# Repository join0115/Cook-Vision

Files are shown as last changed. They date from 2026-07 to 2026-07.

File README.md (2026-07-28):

# 시각장애인용 요리 보조 안경 (YOLO 기반)

대학교 졸업작품(캡스톤 디자인)으로 제작한 프로젝트입니다. 시각은 인간 감각 수용체의
약 70%를 차지하는 가장 중요한 감각이지만, 시각장애인은 그 정보의 부재로 스스로 요리하는
데 어려움을 겪습니다. 이에 안경에 부착한 카메라 영상을 YOLO로 분석해 조리대 위 재료를
인식하고, 사용자가 음성으로 "빵 어디 있어?"라고 물으면 손을 기준으로 몇 시 방향에 있는지
음성으로 안내함으로써, 타인의 도움 없이도 자율적으로 요리할 수 있도록 하는 것을
목표로 했습니다.

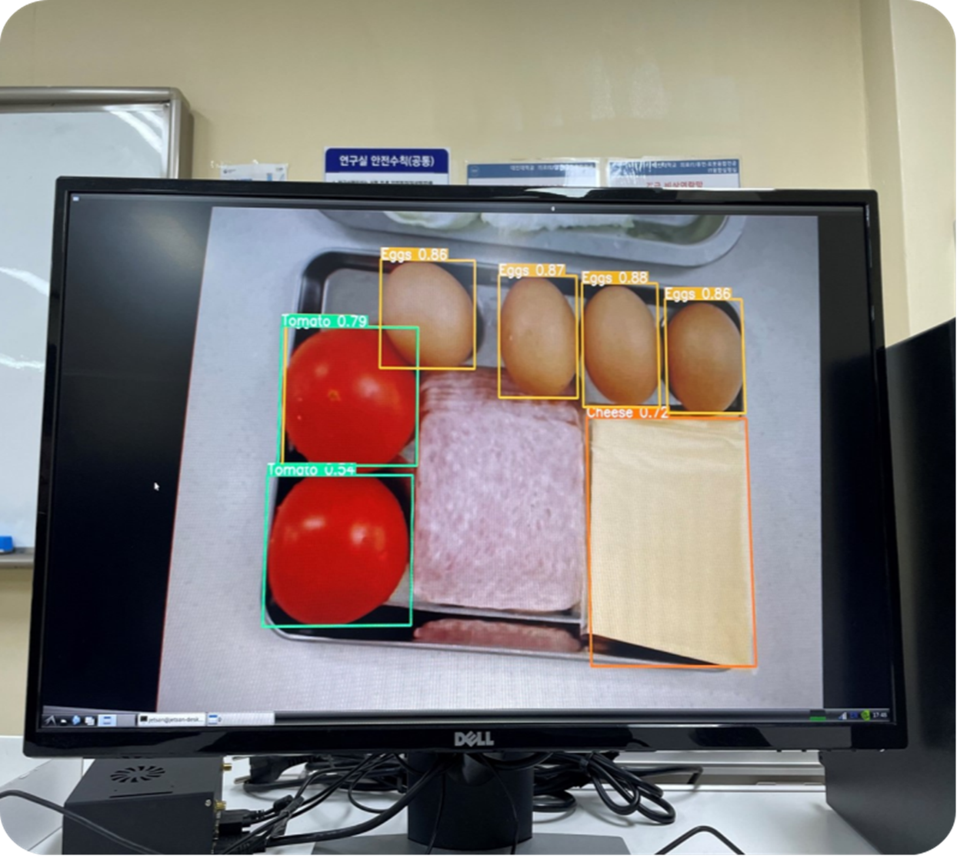
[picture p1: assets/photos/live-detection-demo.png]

*실제 젯슨나노 화면에 라이브로 뜬 YOLOv5 탐지 결과입니다 — 토마토/계란/치즈를 실시간으로 인식하고 있습니다.*
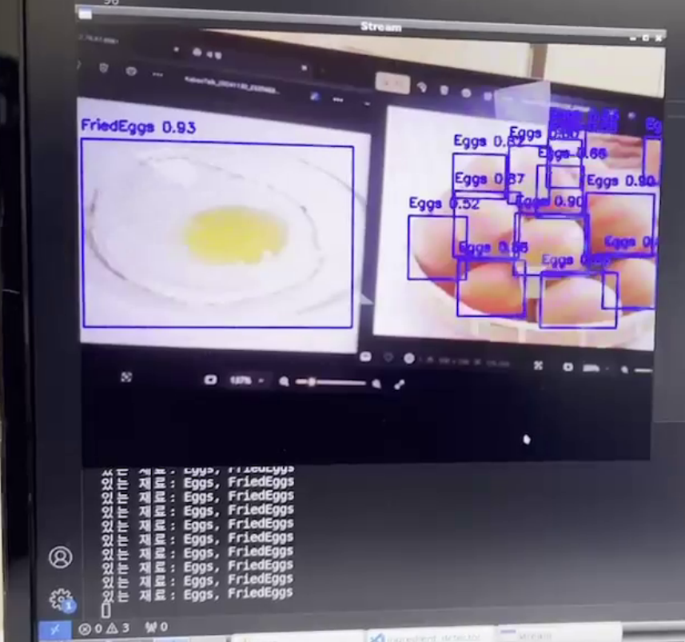
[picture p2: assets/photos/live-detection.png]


## 이 저장소에 대해

원본 프로젝트는 Jetson Nano + Raspberry Pi 두 대의 임베디드 보드에서 동작했는데, 두 보드
모두 하드웨어 오류가 발생하면서 실제 구동 환경과 최신 실행 이력을 잃어버렸습니다.
개발 과정에서 남겨둔 소스 코드 사본이 남아있어, 그것을 다시 분석해서 정리했습니다.

**정리 원칙**: 실제로는 동작하지 않았던 부분을 동작하는 것처럼 꾸미지 않았습니다. 검증
가능한 핵심 기능(`jetson/`, `pi/`)과, 개발 과정에서 시도했지만 완성하지 못한 프로토타입
(`experiments/`)을 명확히 구분했습니다. 무엇을 고쳤고 무엇을 원본 그대로 남겼는지는
[docs/KNOWN_ISSUES.md](./docs/KNOWN_ISSUES.md)에 기록했습니다.

## 기술 스택

- **컴퓨터 비전**: YOLOv5 (커스텀 학습, 클래스: hand/bread/cheese/eggs/friedeggs/ham/lettuce/tomato), OpenCV, PyTorch
- **음성 인식**: Google Cloud Speech-to-Text (스트리밍)
- **웨이크워드 감지**: Picovoice Porcupine
- **음성 출력**: espeak-ng TTS, ALSA(aplay) 기반 사전 녹음 음성 재생
- **통신**: Python 표준 `socket` (TCP) — Jetson Nano ↔ Raspberry Pi
- **하드웨어**: Raspberry Pi(카메라 + ReSpeaker 2 Mics Pi HAT, motionEye로 영상 송출 겸 음성 I/O 담당) + Jetson Nano(스트림을 받아 YOLO 연산만 전담)

## 폴더 구조

```
portfolio/
├── jetson/            # 젯슨나노: YOLO 탐지 + 소켓 서버 (검증된 핵심 기능)
├── pi/                # 라즈베리파이: 음성 인식/출력 + 소켓 클라이언트 (검증된 핵심 기능)
├── experiments/        # 개발 과정 중 시도했던 프로토타입/테스트 (미완성, 각 파일에 이유 명시)
├── assets/
│   ├── voice/         # 음성 안내 mp3/wav 에셋
│   ├── photos/        # 실물/실행 화면 사진
│   └── 3d-model/      # 안경 프레임 3D 모델 (Fusion 360 / STEP / STL) + 렌더 이미지
└── docs/
    ├── ARCHITECTURE.md   # 시스템 구성도 및 실제 검증된 흐름 vs 미완성 흐름
    └── KNOWN_ISSUES.md   # 발견한 버그, 보안 스크러빙 내역, 구조적 문제 기록
```

자세한 시스템 흐름은 [docs/ARCHITECTURE.md](./docs/ARCHITECTURE.md)를 참고해 주세요.

## 사진 & 3D 모델

| | |
|---|---|
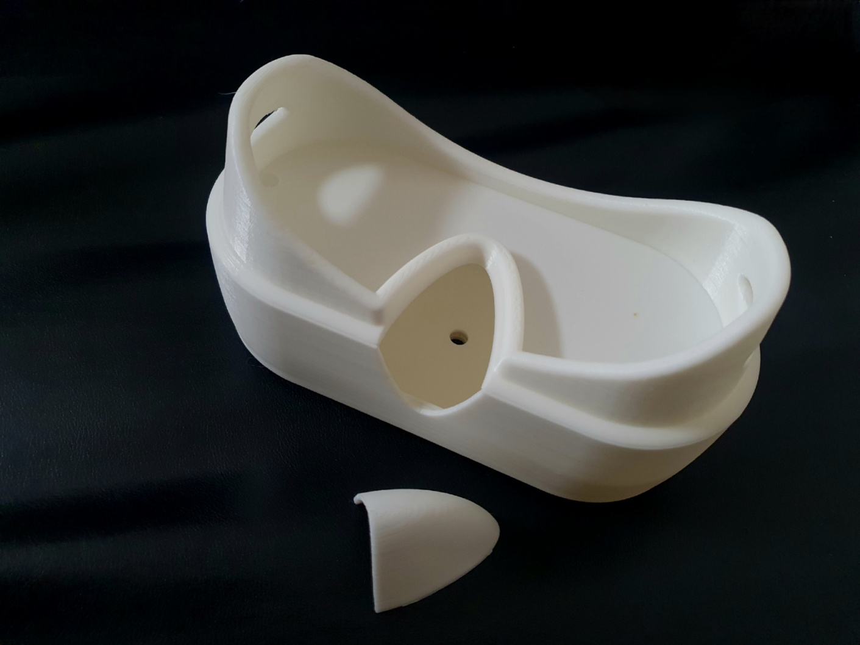
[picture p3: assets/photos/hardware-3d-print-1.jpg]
3D 프린트 출력물 1
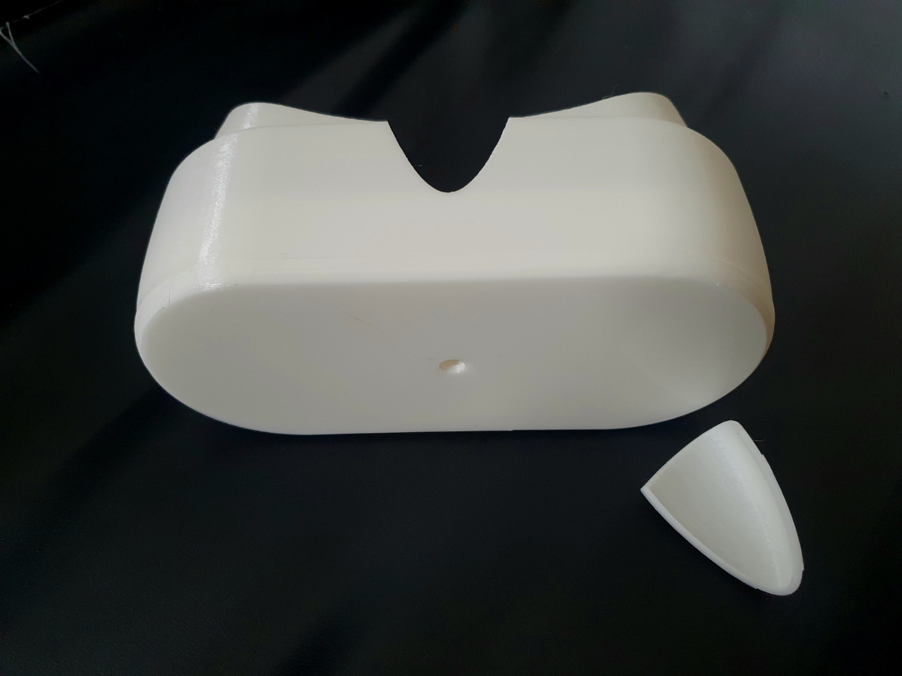
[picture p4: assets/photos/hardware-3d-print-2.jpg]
3D 프린트 출력물 2
|  |  |

3D 프린터로 출력한 안경 프레임 실물입니다. 설계 파일(Fusion 360/STEP/STL)과 렌더 이미지는
[assets/3d-model/](./assets/3d-model/)에 있습니다.

실제 착용한 모습입니다.

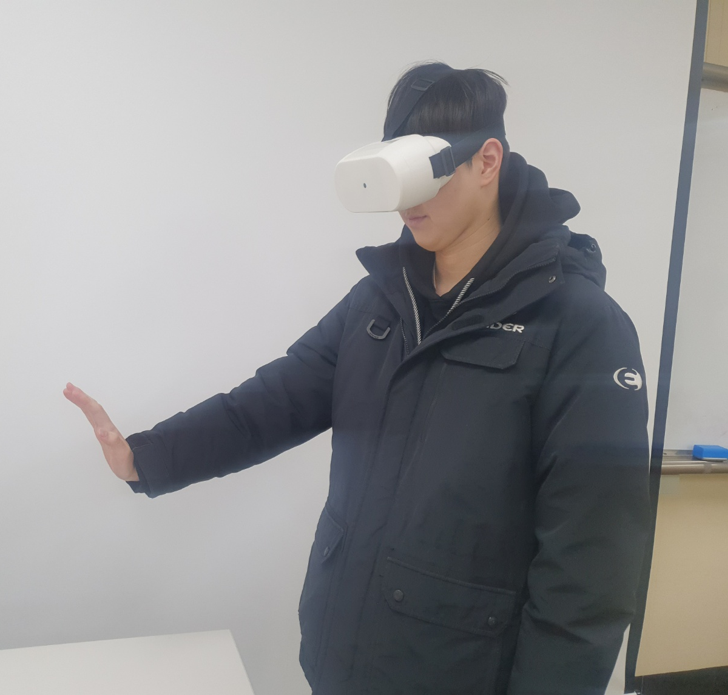
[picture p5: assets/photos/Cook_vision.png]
실제로 착용한 모습


YOLOv5 학습/검증 과정을 보여주는 이미지는 [assets/photos/](./assets/photos/)에 정리했습니다
(`yolo-train-batch.jpg`, `yolo-val-batch-labels.jpg`).

## 실행 방법 (재현 시 참고용)

> 실제 장비(Jetson Nano, Raspberry Pi)와 카메라, 커스텀 학습된 YOLOv5 가중치가 있어야
> 동작합니다. 학습된 가중치 파일(`best.pt`)은 하드웨어 오류로 별도 보관하지 못해 이
> 저장소에 포함되어 있지 않습니다 — 클래스 목록(`jetson/config.py`의 `CLASS_NAMES`)을
> 참고해 동일한 클래스로 재학습이 필요합니다.

1. 두 보드 각각에 `requirements.txt`를 설치합니다.
2. 젯슨나노에는 [YOLOv5 저장소](https://github.com/ultralytics/yolov5)를 별도로 clone해둡니다.
3. `.env.example`을 참고해 `.env`를 만들고, 실제 카메라 스트림 주소·젯슨 IP·학습된
   가중치 경로·Google Cloud 인증 파일 경로·Picovoice 액세스 키 등을 채웁니다.
4. 젯슨나노: `python jetson/ingredient_locator_server.py`
5. 라즈베리파이: `python pi/ingredient_locator_client.py`

## 한계점 / 배운 점

- YOLOv5 재료 탐지는 실제 젯슨나노 하드웨어에서 라이브로 동작을 확인했습니다 (위
  스크린샷 참고). 손 기준 상대 위치를 계산해 시계 방향으로 안내하는 아이디어 자체도
  구현했고, Jetson↔Pi 소켓 통신 + Google STT + 음성 안내까지 각 요소 기술은 개별적으로
  동작을 확인했습니다.
- 다만 웨이크워드 감지(Porcupine)까지 포함한 전체 파이프라인을 하나로 묶어 안정적으로
  자동 실행시키는 마지막 통합 단계는 완성하지 못했습니다. 소켓 통신 구조를 다시
  들여다보니 실험적으로 시도했던 버전 중 하나(`experiments/wake_word_assistant.py`)는
  애초에 Jetson·Pi 양쪽이 모두 서버로 동작해 서로 연결될 수 없는 구조였다는 것도 이번
  정리 과정에서 뒤늦게 발견했습니다.
- 이번 정리를 통해 원본에 있던 실제 로직 버그(12시 방향 판정이 항상 실패하던 체이닝
  비교 버그 등)와 하드코딩된 비밀정보(API 키, 인증 경로)를 찾아내 수정/제거했습니다.

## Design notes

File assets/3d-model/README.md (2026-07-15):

# 3D 모델링 (안경 프레임)

Fusion 360으로 설계한 안경 프레임 하우징입니다. 캡스톤 디자인 원본 폴더의 "3D 모델링"
폴더에서 가져왔습니다 (파일명만 영문으로 정리했고, 내용은 원본 그대로입니다).

- `cooking_assist_glasses.f3d` — Fusion 360 네이티브 파일입니다 (편집 가능).
- `cooking_assist_glasses.step` — STEP 포맷입니다 (다른 CAD 툴에서도 열립니다).
- `cooking_assist_glasses.stl` — 3D 프린팅용 메시입니다 (실제로 이 파일로 출력한 사진은
  [../photos/hardware-3d-print-1.jpg](../photos/hardware-3d-print-1.jpg),
  [../photos/hardware-3d-print-2.jpg](../photos/hardware-3d-print-2.jpg) 참고).
- `render-isometric.png` — 조립된 형태의 아이소메트릭 렌더입니다 (도면 양식).
- `render-exploded-view.png` — 분해도(exploded view)입니다. 위쪽부터 안경 프레임 상단부,
  카메라/센서가 들어가는 중단부, 하단 커버 순서로 3파트 구조임을 보여줍니다.

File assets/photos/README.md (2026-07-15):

# 작품 사진

- `live-detection-demo.png` — 실제 젯슨나노에 연결된 모니터에서 YOLOv5 탐지가 라이브로
  동작하는 화면입니다. 토마토(Tomato), 계란(Eggs), 치즈(Cheese)가 실시간으로 바운딩 박스와
  confidence 점수와 함께 인식되고 있습니다 — 탐지 기능이 실제 하드웨어에서 동작했음을
  보여주는 근거 사진입니다.
- `hardware-3d-print-1.jpg`, `hardware-3d-print-2.jpg` — 3D 프린터로 출력한 실물 안경
  프레임 하우징 사진입니다.
- `yolo-train-batch.jpg` — YOLOv5 학습 중 저장되는 학습 배치 시각화입니다 (`train_batch*.jpg`).
  실제 학습에 사용한 손/재료 사진들과 augmentation 결과를 보여줍니다.
- `yolo-val-batch-labels.jpg` — 검증(validation) 배치의 정답 라벨 시각화입니다. Lettuce,
  FriedEggs, Bread 등 클래스별 라벨이 제대로 붙어있는지 확인하는 용도입니다.

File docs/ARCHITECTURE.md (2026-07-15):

# 시스템 구성

## 하드웨어

안경(웨어러블) 쪽에는 카메라와 라즈베리파이가 함께 붙어있고, 연산이 무거운 YOLO 추론만
별도의 젯슨나노가 담당하는 역할 분담 구조였습니다.

- **Raspberry Pi** (+ 카메라, + ReSpeaker 2 Mics Pi HAT) — 3가지 역할을 겸했습니다.
  1. 카메라로 영상을 캡처
  2. motionEye로 그 영상을 MJPEG 스트림으로 송출 (`http://<Pi IP>:8081`)
  3. 마이크 입력, 음성 인식/출력, 스피커 재생 (`pi/ingredient_locator_client.py`)
- **Jetson Nano** — 라즈베리파이가 송출한 스트림을 `cv2.VideoCapture()`로 받아와 YOLOv5로
  재료/손 탐지만 전담합니다. 카메라나 motionEye를 직접 실행하지는 않습니다.

즉 카메라를 "들고 있는" 쪽과 "영상을 분석하는" 쪽이 물리적으로 분리되어 있어, 안경(라즈베리파이
+ 카메라)은 가볍게 사용자가 착용하고, 연산이 무거운 젯슨나노는 별도로(가방 등에) 둘 수 있는
구조였던 것으로 보입니다.

## 의도된 전체 흐름

```
[Raspberry Pi + 카메라] --motionEye로 캡처/송출--> MJPEG 스트림 (http://<Pi IP>:8081)
                                                        │
                                                        ▼
                                              [Jetson Nano]
                                    │  스트림을 가져와 YOLOv5로 hand + 재료
                                    │  (bread/cheese/eggs/friedeggs/ham/lettuce/tomato) 탐지
                                    │  소켓 서버로 대기 (0.0.0.0:65432)
                                    │
                                    ▼
[Raspberry Pi] --마이크 입력--> Google STT --재료명--> 소켓으로 Jetson에 전송
      │                                                        │
      │                              <--"있음/없음" + n시 방향-- │
      ▼
  안내 음성(mp3/wav) 재생 (재료명 → 방향 순서)
```

같은 라즈베리파이가 위쪽(카메라 송출)과 아래쪽(음성 인식/출력) 역할을 동시에 맡는 구조라,
`jetson/config.py`의 `CAMERA_STREAM_URL`은 실제로는 라즈베리파이의 IP를 가리켜야 합니다.

## 검증된(실제 동작이 확인되는) 흐름

- `jetson/ingredient_locator_server.py` (원본 JetDo.py) — 소켓 **서버**입니다. 재료명을
  받아 YOLOv5 탐지 후 "재료 있음/없음" + 시 방향을 응답합니다.
- `pi/ingredient_locator_client.py` (원본 PiDo.py) — 소켓 **클라이언트**입니다. Google
  STT로 재료명을 인식해 서버에 전송하고, 응답을 받아 안내 음성을 재생합니다.

두 파일은 host/port, 요청·응답 프로토콜이 정확히 맞물리는 유일한 조합이라, 실제로
전원을 켜면 자동 실행되던 조합이었을 가능성이 가장 높습니다. (단, 사용자 본인 확인으로도
"기능을 완성시키지는 못했다"고 하여, 끝까지 안정적으로 통합·디버깅되었는지는 불확실합니다.)

## 미완성으로 남은 흐름

`experiments/wake_word_assistant.py` (원본 end/pi_1.py)는 "웨이크워드 → STT 명령 인식
→ TTS 응답"까지 파이 쪽에서 전부 처리하려던 더 발전된 버전으로 보입니다. 하지만 이 파일은
파이 쪽도 소켓 **서버**로 열어놓기 때문에, 역시 서버인 `ingredient_locator_server.py`와는
애초에 연결될 수 없는 구조입니다. 즉 두 컴포넌트 모두 "연결을 기다리기만" 하고 있어 실제로는
서로 대화가 불가능했습니다. `handle_command()` 함수도 "where is" 명령을 인식만 하고 실제
동작은 비어 있는 TODO 상태였습니다.

정리하면, 이 프로젝트는 (1) YOLOv5 기반 손-재료 상대 위치 탐지, (2) Google STT 기반 음성
명령 인식, (3) Porcupine 웨이크워드 감지, (4) TCP 소켓 기반 Jetson↔Pi 통신, (5) 음성
안내 재생까지 각 요소 기술은 개별적으로 구현했지만, 이 모든 것을 하나의 안정적인
자동 실행 파이프라인으로 완전히 통합하는 마지막 단계는 마치지 못한 상태로 남아 있습니다.
자세한 근거는 [KNOWN_ISSUES.md](./KNOWN_ISSUES.md)를 참고해 주세요.

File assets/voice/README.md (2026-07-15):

# 음성 안내 에셋

`pi/ingredient_locator_client.py` 등에서 재생하는 안내 음성(mp3/wav) 모음입니다.

## 포함된 폴더

- `clock/` — 1~12시 방향 안내 (24개 = 12 × mp3/wav)
- `ingredient/` — 재료명 안내: bread, cheese, egg, ham, lettuce, tomato (각 mp3/wav)
- `recipe/` — 샌드위치 레시피 안내 1~4단계
- `step_1/`, `step_2/`, `step_3/`, `step_4/` — 단계별 진행 안내

## 원본에서 제외한 것

원본 `베트남 코드/voice/` 안에는 위 폴더들과 거의 동일한 내용이지만 파일명 끝에
공백이 붙은 중복 폴더가 별도로 있었습니다 (`_clock/`, `_ingredient/`, `_step_1/`~`_step_4/`,
예: `"1 .mp3"`처럼 숫자와 확장자 사이에 공백). OS별 파일 복사 과정에서 생긴 것으로 보이는
사실상 동일한 사본이라 포트폴리오 정리본에는 포함하지 않았습니다.

## 알려진 불일치 (docs/KNOWN_ISSUES.md 참고)

`베트남 코드/PiDo.py` 원본 코드는 `voice/ingredients/Bread.wav`처럼 **복수형 폴더명 +
대문자 시작 파일명**을 참조하지만, 실제 존재하는 파일은 `voice/ingredient/bread.wav`처럼
**단수형 폴더명 + 소문자 파일명**입니다. 또한 `step_4/invalid_ingredient.wav`도 코드에는
참조되지만 실제로는 존재하지 않습니다. 프로젝트가 끝까지 통합 테스트되지 못했음을 보여주는
증거라서 임의로 파일명을 바꾸지 않고 그대로 두었습니다.

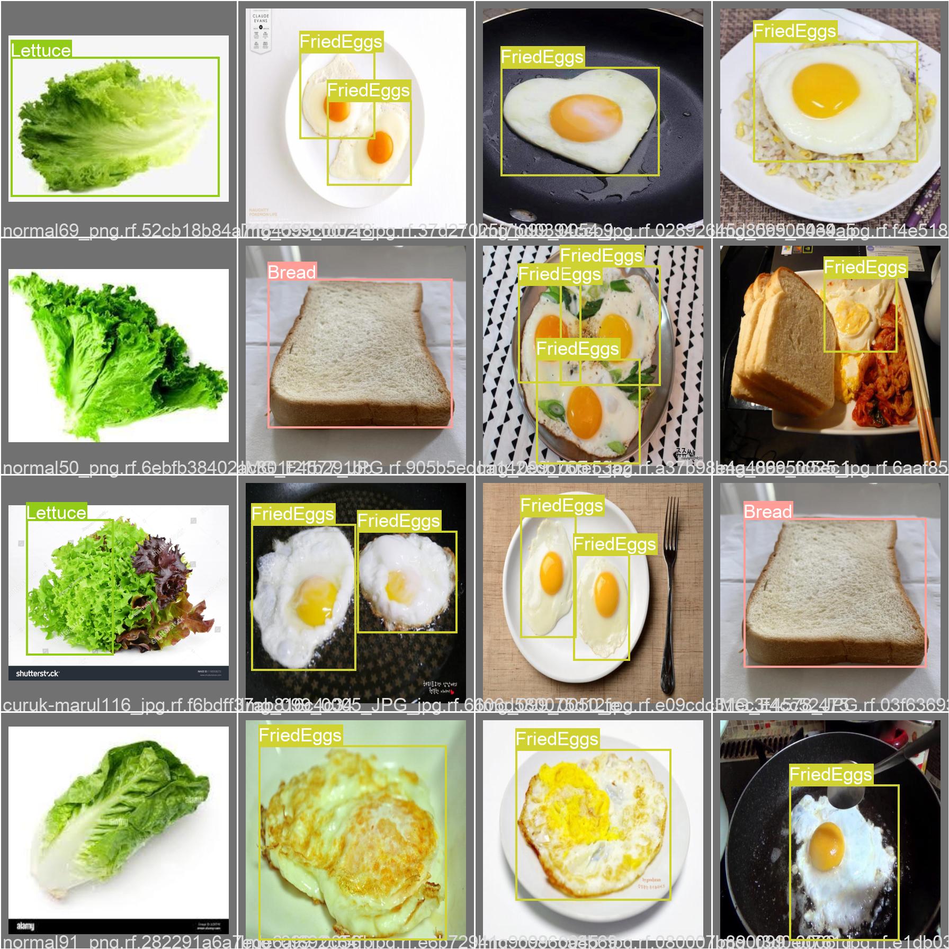
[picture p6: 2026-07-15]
assets/photos/yolo-val-batch-labels.jpg

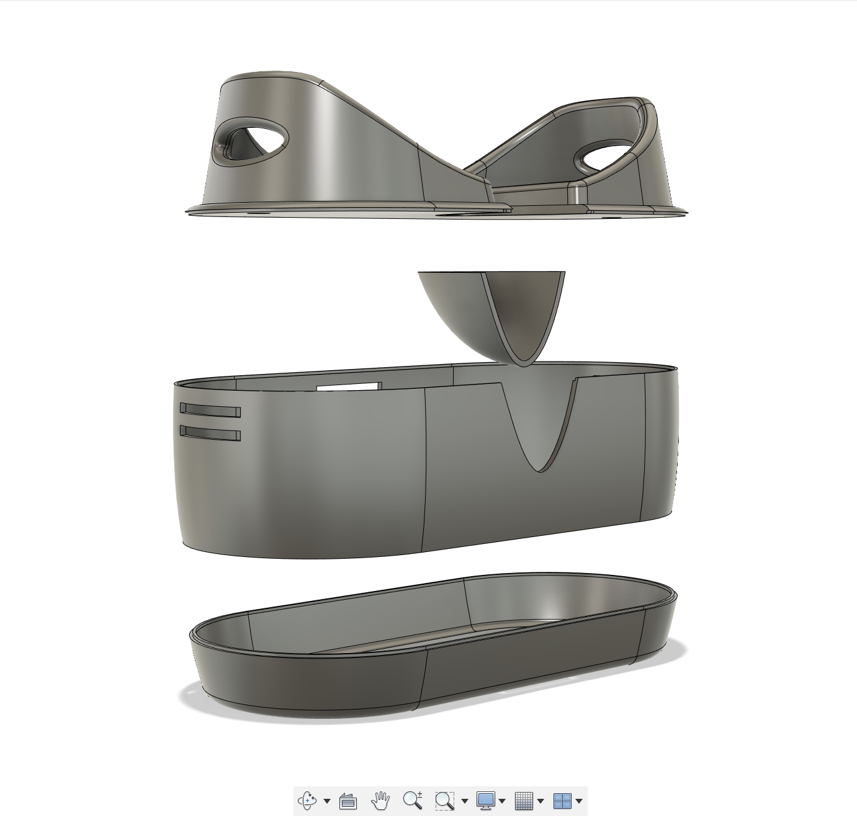
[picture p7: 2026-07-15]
assets/3d-model/render-exploded-view.png

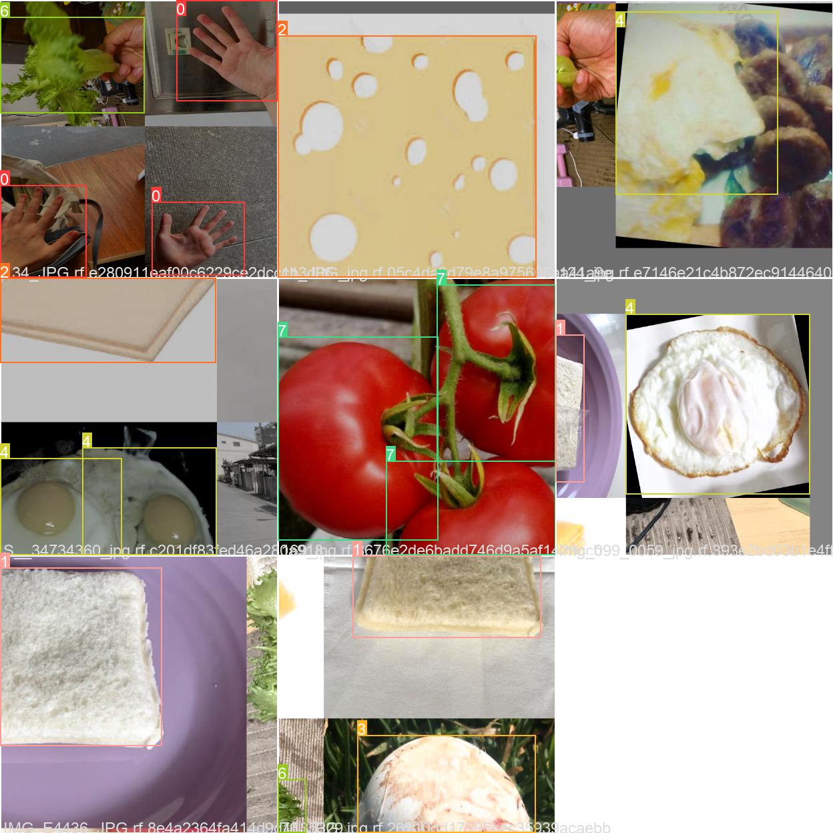
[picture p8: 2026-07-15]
assets/photos/yolo-train-batch.jpg

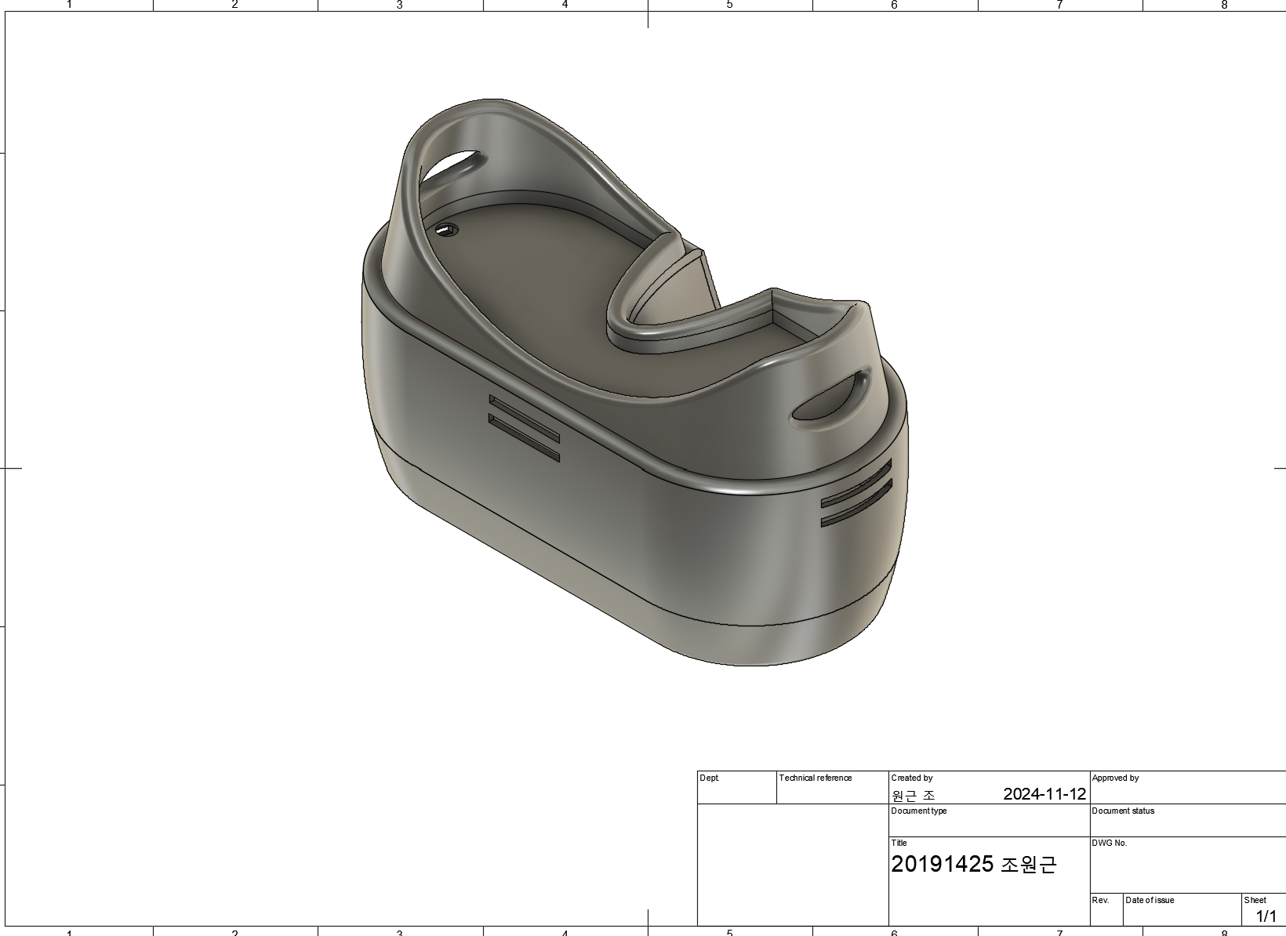
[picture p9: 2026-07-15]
assets/3d-model/render-isometric.png

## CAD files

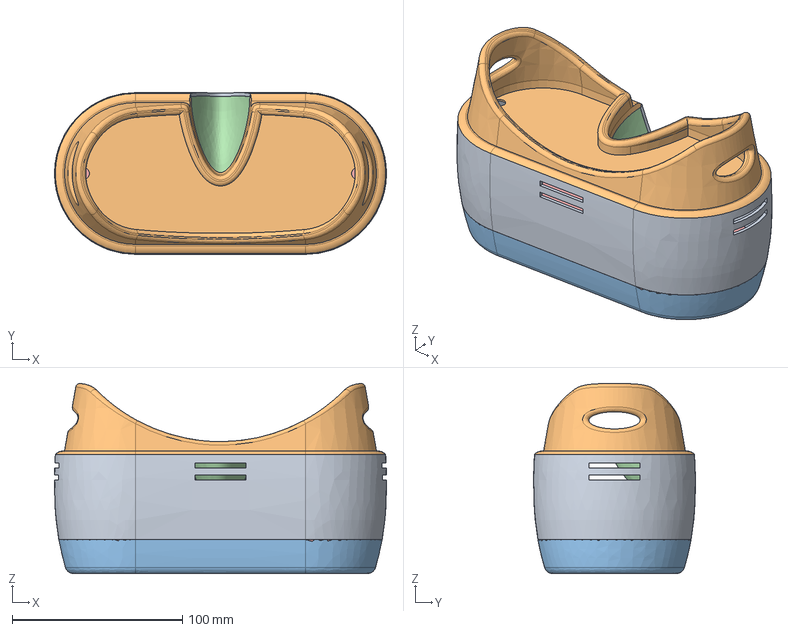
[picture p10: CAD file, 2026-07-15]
assets/3d-model/cooking_assist_glasses.step
195.0 x 95.0 x 111.7 mm
L
nose
s

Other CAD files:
assets/3d-model/cooking_assist_glasses.f3d
assets/3d-model/cooking_assist_glasses.stl

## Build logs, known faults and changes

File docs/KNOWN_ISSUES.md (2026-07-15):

# 정리 과정에서 발견한 이슈

원본 코드(하드웨어 오류로 실행 환경은 소실, 소스 사본만 남아있던 상태)를 분석하며 발견한
버그/보안 이슈/구조적 문제를 정리한 기록입니다. 포트폴리오 코드 자체에서 고친 것과, 일부러
원본 그대로 남겨둔 것을 구분해서 적었습니다.

## 1. 수정한 버그

### 12시 방향 판정 버그 (체이닝 비교)
`jetson/ingredient_locator_server.py`, `jetson/location_detector.py` 등 여러 파일에
아래와 같은 코드가 있었습니다.

```python
if 345 <= angle < 15:
    direction = "12"
```

파이썬에서 `345 <= angle < 15`는 `(345 <= angle) and (angle < 15)`로 해석됩니다.
`angle`은 0~360 범위의 값이라 이 두 조건을 동시에 만족하는 값은 존재하지 않습니다.
즉 12시 방향 분기가 **항상 실행되지 않는** 죽은 코드였고, 각도가 345~360 또는 0~15
범위일 때는 `direction` 변수가 아예 할당되지 않아 이후 코드에서 `NameError`가 나거나
(`ingredient_locator_server.py`) `direction`이 없는 채로 넘어가는 상황이 발생했습니다.

→ `angle >= 345 or angle < 15`로 수정했습니다 (jetson/ 폴더의 정식 버전에만 적용).
`experiments/location_detector_debug_viewer.py`(원본 jet_step_4_1.py)는 프로토타입
원본 보존 차원에서 버그를 그대로 남겨두고 주석으로만 설명했습니다.

### "정리된" 버전에만 있던 3시/9시 스왑 버그
`캡스톤 코드 파일/location_detector.py`(정리된 듯 보였던 사본)에는 `베트남 코드` 쪽
원본에는 없는 별도의 버그가 있었습니다 — 3시 방향과 9시 방향 판정 각도 구간이 서로
뒤바뀌어 있었습니다. 그래서 포트폴리오 정리본은 `베트남 코드/jetson/location_detector.py`를
기준으로 삼았습니다.

## 2. 스크러빙한 보안 이슈 (🚨 실제 노출된 값)

| 항목 | 원본 위치 | 조치 |
|---|---|---|
| Picovoice(Porcupine) 액세스 키 (평문) | `pi/porcupine.py`, `캡스톤 코드 파일/porcupine.py`, `end/pi_1.py` (총 3곳, 전부 동일한 키) | 환경변수 `PICOVOICE_ACCESS_KEY`로 치환. **원본 키는 코드에서 완전히 제거했으며, 실제 프로젝트에서 재사용 중이라면 Picovoice 콘솔에서 재발급을 권장합니다** |
| Google Cloud 프로젝트 ID가 노출된 인증 파일 경로 (`key-rider-443318-h3-...json`) | `PiDo.py`, `pi/googole_stt.py`, `pi/STTest.py` (파일마다 경로가 조금씩 다름) | 환경변수 `GOOGLE_APPLICATION_CREDENTIALS`로 치환 |
| 젯슨/카메라 내부 네트워크 IP 4~5개 (`10.2.76.67`, `192.168.6.235`, `192.168.0.19`, `10.2.74.234`, `192.168.6.191`, `10.2.79.121`) | 거의 모든 파일 | 환경변수(`CAMERA_STREAM_URL`, `JETSON_HOST` 등)로 치환 |

## 3. 구조적 문제 (원본 그대로 두고 문서화만 함)

- **Pi가 서버 역할을 하는 버전과 클라이언트 역할을 하는 버전이 공존**: `PiDo.py`(클라이언트)와
  `end/pi_1.py`(서버) 두 가지 아키텍처 시도가 있었는데, 젯슨 쪽(`JetDo.py`)이 항상 서버였기
  때문에 `end/pi_1.py` 쪽은 애초에 연결이 불가능했습니다. → `docs/ARCHITECTURE.md` 참고.
- **`jetson/main.py`가 양쪽 폴더 모두 빈 파일(0바이트)**: 각 기능(YOLO 탐지, 소켓 서버)을
  하나로 묶는 진입점을 만들 계획이었으나 구현되지 않았고, 대신 `JetDo.py`가 사실상 그
  역할을 대신한 것으로 보입니다. 포트폴리오에서는 존재하지 않았던 통합을 지어내지 않고,
  `jetson/ingredient_locator_server.py`를 진입점으로 명시했습니다.
- **음성 파일 경로 불일치**: `PiDo.py`는 `voice/ingredients/Bread.wav`(복수형 폴더 +
  대문자)를 참조하지만 실제 에셋은 `voice/ingredient/bread.wav`(단수형 + 소문자)이고,
  `step_4/invalid_ingredient.wav`는 아예 존재하지 않습니다. → `assets/voice/README.md` 참고.
  실제 재현 시 조정이 필요한 부분이라 일부러 고치지 않았습니다.
- **`STTest.py`의 "next" vs "where is" 불일치**: 안내 문구는 "next"라고 말하라고 하지만
  실제 판정 로직은 "where is" 포함 여부만 검사합니다. `experiments/stt_two_stage_test.py`에
  주석으로 남겨두고 수정하지 않았습니다.

## 4. 중복 파일 정리

`베트남 코드/jetson/`과 `캡스톤 코드 파일/`에 `ingredient_detector.py`, `motioneye.py`,
`socket.py`가 스트림 IP만 다른 채 거의 동일하게 중복되어 있었습니다. `pi/porcupine.py`는
두 폴더에 완전히 동일한(byte-identical) 사본으로 존재했습니다. 포트폴리오에는 각각 한 벌만
남기고, 중복이었다는 사실만 이 문서에 기록했습니다.

## 5. 기타 정리한 죽은 코드

- `jetson/ingredient_detector.py`(원본)의 어디에서도 쓰이지 않던 `required_ingredients`
  리스트를 제거했습니다.
- `pi/pi_socket.py`(원본) 하단에 통째로 주석 처리되어 있던 실험용 대체 구현을 삭제했습니다.
- `pi/espeak_ng.py`(원본)의 미사용 `sleep` import, 주석 처리된 독일어 예시를 삭제했습니다.
- `jetson/socket.py` → `experiments/socket_echo_test.py`로 리네임했습니다 (표준 라이브러리
  `socket` 모듈과 이름이 겹쳐 import 충돌을 일으킬 수 있는 문제였습니다).
